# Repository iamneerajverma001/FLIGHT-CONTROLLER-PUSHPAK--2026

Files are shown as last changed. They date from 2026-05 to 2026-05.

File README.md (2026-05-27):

# Pushpak Flight Controller (FCV3)





[Download PCB ZIP](https://github.com/iamneerajverma001/FLIGHT-CONTROLLER-PUSHPAK--2026/archive/refs/heads/main.zip) · One-click download
[Open Portfolio App](https://cv6gnv.csb.app) · One-click interactive project summary

Quick links: [Visuals](#visuals) | [System overview](#system-overview) | [Core specs](#core-hardware-specifications) | [Block diagram](#block-diagram) | [Manufacturing](#manufacturing) | [Architecture](#architecture-deep-dive)

Pushpak FCV3 is a 36x36mm, 4-layer, noise-optimized flight controller built for high-performance FPV and autonomous payload delivery.

## Visuals
| Top view | Bottom view |
| --- | --- |
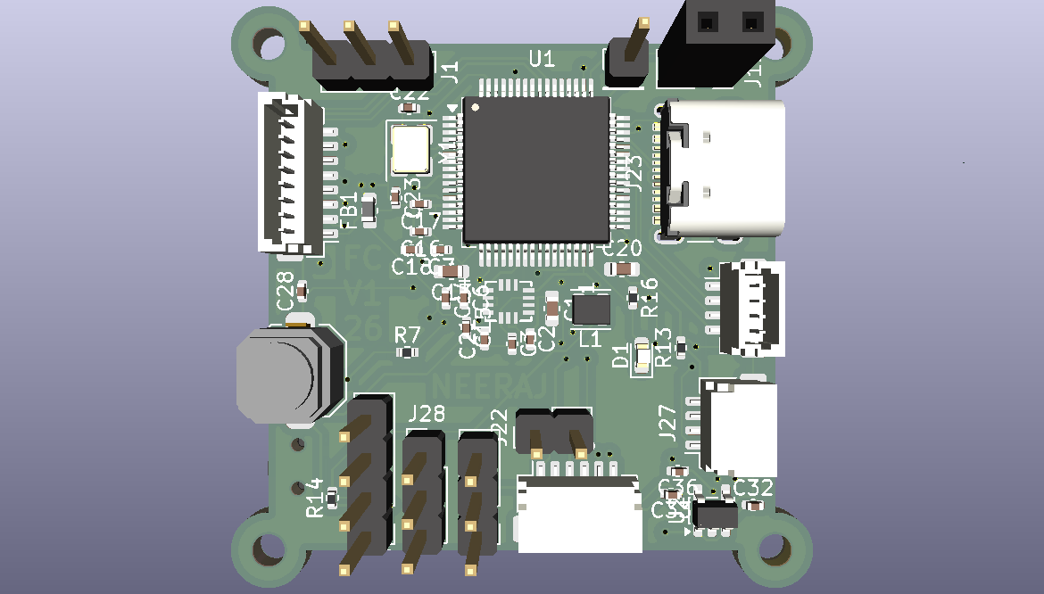
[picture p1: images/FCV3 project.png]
Top view
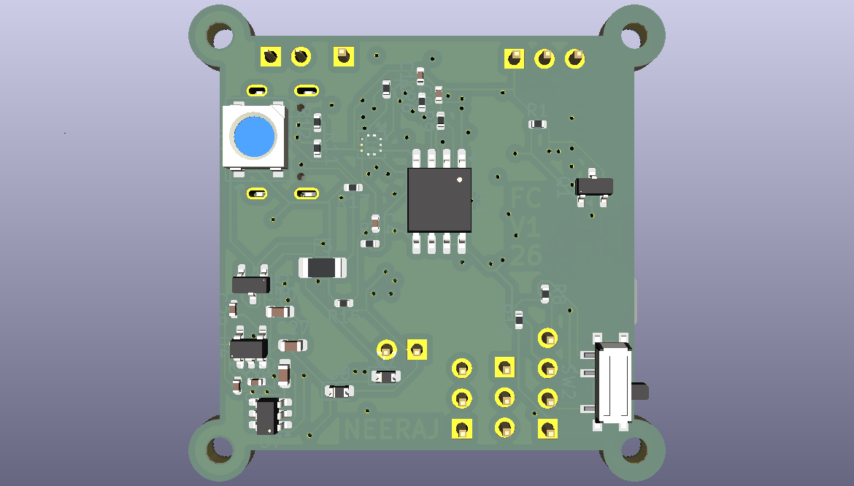
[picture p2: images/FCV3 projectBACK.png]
Bottom view
|  |  |

## System overview
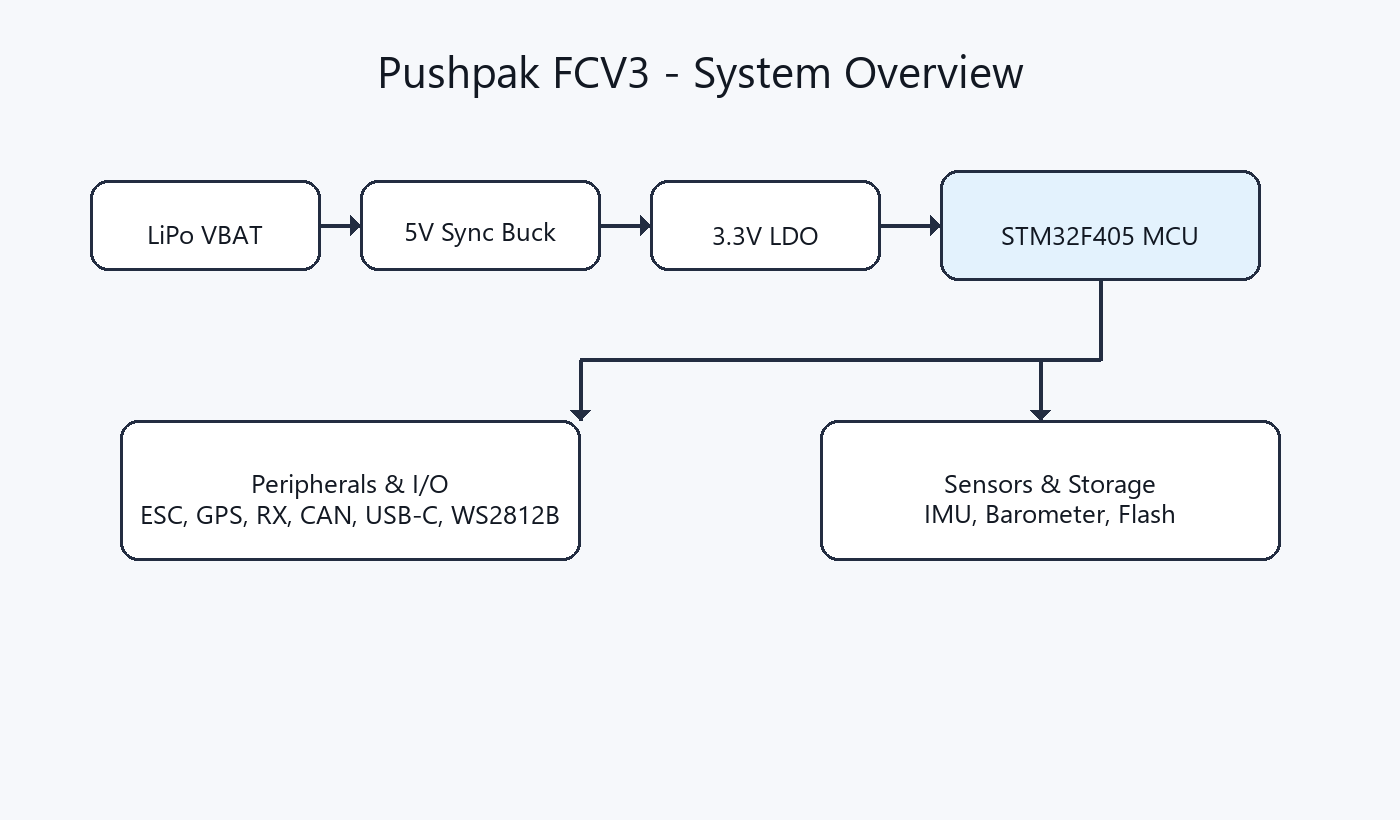
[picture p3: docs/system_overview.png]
System overview


## Key assets
| Asset | Location |
| --- | --- |
| KiCad project | [hardware/FCV3 project.kicad_pro](hardware/FCV3%20project.kicad_pro) |
| Architecture deep dive | [docs/HARDWARE_ARCHITECTURE.md](docs/HARDWARE_ARCHITECTURE.md) |
| System overview graphic | [docs/system_overview.png](docs/system_overview.png) |
| 3D model (VRML) | [outputs/FCV3 project.wrl](outputs/FCV3%20project.wrl) |
| Portfolio web app | [Open Portfolio App](https://cv6gnv.csb.app) |

## 3D model
- Board model (VRML): [outputs/FCV3 project.wrl](outputs/FCV3%20project.wrl)

## Block diagram
```mermaid
flowchart LR
  VBAT["LiPo VBAT"] --> BUCK["5V Sync Buck"]
  BUCK --> LDO["3.3V LDO"]
  LDO --> MCU["STM32F405"]
  MCU -->|SPI| IMU["ICM-42688-P"]
  MCU -->|I2C/SPI| BARO["BMP280 / BMP390"]
  MCU -->|SPI| FLASH["W25Q128"]
  MCU -->|Timers/DMA| ESC["4-in-1 ESC - DShot"]
  MCU -->|UART| GPS["GPS"]
  MCU -->|UART| RX["Radio Receiver"]
  MCU -->|CAN| CAN["DroneCAN"]
  MCU -->|USB| USBC["USB-C"]
  MCU -->|GPIO + BSS138| LED["WS2812B LEDs"]
```

## Core hardware specifications
- Processor: STM32F405RGT6 (ARM Cortex-M4) for high-speed calculation.
- IMU (Gyro): ICM-42688-P running on a dedicated ultra-fast SPI bus.
- Barometer: BMP280 / BMP390 for altitude hold.
- Blackbox: W25Q128 (16MB Flash) for flight data logging.
- Power delivery: High-efficiency 5V synchronous buck converter (MP1584 / TPS54202) taking raw LiPo voltage, paired with a clean 3.3V LDO for logic.

## Connectivity & I/O
- Motor control: 4-in-1 ESC connector (J21) with full hardware timer and DMA support for zero-latency DShot600.
- Expansions: DroneCAN telemetry, dedicated GPS port, and Radio Receiver port.
- Extras: WS2812B LED output (via BSS138 5V logic shifter) and USB-C for configuration.

## Repository navigation & usage
- hardware/ - KiCad project, schematic, PCB, and library tables.
- libraries/ - Custom symbols, footprints, and 3D models.
- outputs/ - BOM, reports, and manufacturing/export files.
- images/ - Board renders and screenshots.
- docs/ - Deep-dive design notes.

## How to open
1. Clone the repository.
2. Open [hardware/FCV3 project.kicad_pro](hardware/FCV3%20project.kicad_pro) in KiCad 8.0.

## Outputs
- BOM: [outputs/FCV3 project.csv](outputs/FCV3%20project.csv)
- ERC report: [outputs/ERC.rpt](outputs/ERC.rpt)
- Design report: [outputs/report.txt](outputs/report.txt)

## Manufacturing
Fabrication exports (Gerbers and Pick & Place/CPL) can be generated into outputs/ when you are ready to manufacture.

## Architecture deep dive
See the design intent and layout strategy in [docs/HARDWARE_ARCHITECTURE.md](docs/HARDWARE_ARCHITECTURE.md).

## Pinout quick view
For the full pinout tables, see [docs/HARDWARE_ARCHITECTURE.md](docs/HARDWARE_ARCHITECTURE.md).

### Core sensors and buses
| Feature | MCU Pin | Bus | Component |
| --- | --- | --- | --- |
| Gyro CS | PA4 | SPI1 | ICM-42688-P |
| Gyro SCK | PA5 | SPI1 | ICM-42688-P |
| Gyro MISO | PA6 | SPI1 | ICM-42688-P |
| Gyro MOSI | PA7 | SPI1 | ICM-42688-P |
| Flash CS | PA15 | SPI3 | W25Q128 |
| Flash SCK | PC10 | SPI3 | W25Q128 |
| Flash MISO | PC11 | SPI3 | W25Q128 |
| Flash MOSI | PC12 | SPI3 | W25Q128 |
| Baro SCL | PA8 | I2C3 | BMP280 / BMP390 |
| Baro SDA | PC9 | I2C3 | BMP280 / BMP390 |

### Motor and payload outputs
| Output | MCU Pin | Timer | Connection |
| --- | --- | --- | --- |
| Motor 1 | PB3 | TIM2_CH2 | J21 ESC port |
| Motor 2 | PB10 | TIM2_CH3 | J21 ESC port |
| Motor 3 | PB2 | TIM2_CH4 | J21 ESC port |
| Motor 4 | PB4 | TIM3_CH1 | J21 ESC port |
| Motor 5 | PB0 | TIM3_CH3 | Expansion |
| Motor 6 | PB14 | TIM12_CH1 | Expansion |
| Servo 1 | PB15 | TIM12_CH2 | Payload / gimbal |

## Challenges & learnings
- Stackup discipline and clean partitioning were critical to keeping gyro noise low.
- Layout geometry matters as much as routing for flight stability.
- Tight power loops and ground shielding reduced EMI from the buck stage.

## License
Project files are licensed under [LICENSE](LICENSE).
Library components are provided under the terms in [license.txt](license.txt).

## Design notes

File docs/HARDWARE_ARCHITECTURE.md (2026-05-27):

# Hardware Architecture

This document focuses on the design intent behind the layout, stackup, and signal integrity choices.

## Visual references
- Renders: ../images/FCV3 project.png (top), ../images/FCV3 projectBACK.png (bottom).
- 3D model: ../outputs/FCV3 project.wrl.
- System overview: system_overview.png.

## Design goals
- Keep sensor noise low while maintaining fast control loop response.
- Maintain short, direct high-speed routes for the gyro and flash.
- Isolate power switching energy from sensitive analog rails.

## Block diagram
```mermaid
flowchart LR
  VBAT["LiPo VBAT"] --> BUCK["5V Sync Buck"]
  BUCK --> LDO["3.3V LDO"]
  LDO --> MCU["STM32F405"]
  MCU -->|SPI| IMU["ICM-42688-P"]
  MCU -->|I2C/SPI| BARO["BMP280 / BMP390"]
  MCU -->|SPI| FLASH["W25Q128"]
  MCU -->|Timers/DMA| ESC["4-in-1 ESC - DShot"]
  MCU -->|UART| GPS["GPS"]
  MCU -->|UART| RX["Radio Receiver"]
  MCU -->|CAN| CAN["DroneCAN"]
  MCU -->|USB| USBC["USB-C"]
  MCU -->|GPIO + BSS138| LED["WS2812B LEDs"]
```

## Master MCU pinout mapping (STM32F4 series)

### Core sensors (internal buses)
| Feature | MCU Pin | Bus / Timer | Component / Function |
| --- | --- | --- | --- |
| Gyro CS | PA4 | SPI1 | ICM-42688-P chip select |
| Gyro SCK | PA5 | SPI1 | ICM-42688-P clock |
| Gyro MISO | PA6 | SPI1 | ICM-42688-P data out |
| Gyro MOSI | PA7 | SPI1 | ICM-42688-P data in |
| Flash CS | PA15 | SPI3 | W25Q128 blackbox chip select |
| Flash SCK | PC10 | SPI3 | W25Q128 blackbox clock |
| Flash MISO | PC11 | SPI3 | W25Q128 blackbox data out |
| Flash MOSI | PC12 | SPI3 | W25Q128 blackbox data in |
| Baro SCL | PA8 | I2C3 | BMP280 / BMP390 clock |
| Baro SDA | PC9 | I2C3 | BMP280 / BMP390 data |

### Propulsion and actuation (DShot and PWM)
| Feature | MCU Pin | Hardware Timer | Physical Connection |
| --- | --- | --- | --- |
| Motor 1 | PB3 | TIM2_CH2 | J21 (4-in-1 ESC port) |
| Motor 2 | PB10 | TIM2_CH3 | J21 (4-in-1 ESC port) |
| Motor 3 | PB2 | TIM2_CH4 | J21 (4-in-1 ESC port) |
| Motor 4 | PB4 | TIM3_CH1 | J21 (4-in-1 ESC port) |
| Motor 5 | PB0 | TIM3_CH3 | Expansion / standalone ESC |
| Motor 6 | PB14 | TIM12_CH1 | Expansion / standalone ESC |
| Servo 1 | PB15 | TIM12_CH2 | Payload drop / camera gimbal |

### Serial connectivity (UART and I2C)
| Feature | MCU Pin | Protocol | Dedicated Function |
| --- | --- | --- | --- |
| GPS TX | PA0 | UART4 | M10/M9 GPS module RX |
| GPS RX | PA1 | UART4 | M10/M9 GPS module TX |
| Radio TX | PA9 | USART1 | ELRS / Crossfire RX |
| Radio RX | PA10 | USART1 | ELRS / Crossfire TX / SBUS |
| ESC RX | PC7 | USART6 | ESC digital telemetry (J21) |
| Ext SCL | PB6 | I2C1 | External compass clock (pulled up) |
| Ext SDA | PB7 | I2C1 | External compass data (pulled up) |
| CAN RX | PB12 | CAN2 | DroneCAN expansion |
| CAN TX | PB13 | CAN2 | DroneCAN expansion |

### Analog inputs (ADC) and lighting
| Feature | MCU Pin | Filter Type | Physical Connection |
| --- | --- | --- | --- |
| Current sensor | PC0 | RC low-pass | ADC1_IN0 (J21 ESC port) |
| Voltage / RSSI | PC5 | RC low-pass | ADC2_IN / VBAT sense |
| Status LED | PB5 | 5V logic shifter | WS2812B data in |

### System and debug
| Feature | MCU Pin | Function | Physical Connection |
| --- | --- | --- | --- |
| USB D- | PA11 | USB-FS | USB-C connector |
| USB D+ | PA12 | USB-FS | USB-C connector |
| SWDIO | PA13 | SWD debug | J11 debug pads |
| SWCLK | PA14 | SWD debug | J11 debug pads |
| OSC IN | PH0 | 8MHz HSE | External crystal |
| OSC OUT | PH1 | 8MHz HSE | External crystal |

## Peripheral mapping and I/O connectivity

### Propulsion and ESC integration (J21 connector)
- Motor outputs (M1 - M4) are mapped to hardware timers (TIM2/TIM3) with DMA support for DShot600 and bidirectional DShot.
- Current sensor input is routed through a dedicated RC low-pass filter before the STM32 ADC.
- VBAT enters the bottom-layer power plant for 5V regulation.

### Radio and telemetry (digital standard)
- Radio receiver port (USART1) is optimized for ELRS, Crossfire, and SBUS. Analog RSSI pads are intentionally omitted.
- ESC telemetry (USART6) provides digital RPM, temperature, and error data from modern ESCs.

### Autonomous navigation (GPS and compass)
- GPS interface (UART4) is dedicated to M10/M8/M9 modules.
- External magnetometer (I2C1) is exposed with onboard 4.7k pull-ups.

### Payload and actuation expansions
- WS2812B LED data is driven through a BSS138 level shifter for reliable 5V signaling.
- Servo and payload PWM pads use hardware timers (TIM12) for deterministic control.

### Configuration and debugging
- USB-C provides high-reliability USB-FS for configuration and logging.
- Bootloader access is supported by a physical BOOT0 button tied to 3.3V.
- SWDIO and SWCLK pads enable bare-metal debugging and firmware bring-up.

## PCB stackup strategy (4-layer strict standard)
- Layer 1 (Top / F.Cu) - The Quiet Zone. This layer hosts the MCU, sensors, and the highest-speed data traces only.
- Layer 2 (Inner 1) - The Shield. A solid GND plane that shields the sensitive top layer from bottom-layer noise.
- Layer 3 (Inner 2) - Power Routing. Dedicated 3V3 and 5V copper polygons for low-impedance delivery.
- Layer 4 (Bottom / B.Cu) - The Power & Noise Zone. High-current VBAT routing and the buck converter stay here.

## Component placement & layout logic
- Gyro positioning: The ICM-42688-P is placed at the geometric center of the 36x36mm board for balanced flight physics.
- MCU orientation: The STM32 is rotated so its SPI1 pins face the gyro, keeping critical traces short and straight.
- Power supply isolation: The 5V buck converter, inductor, and diode are clustered in a single bottom-layer corner to confine magnetic noise.
- Thermal management: The barometer sits in the corner opposite the power supply to reduce heat-induced altitude drift.

## Signal integrity & noise immunity
- Analog low-pass filtering: Ferrite bead + multi-cap decoupling on VDDA and current sensor lines scrub ESC noise before the ADC.
- Decoupling strategy: All 0.1uF caps are placed directly under MCU pins and via'd straight down to minimize loop inductance.
- Logic level shifting: A BSS138 N-channel MOSFET shifts 3.3V MCU GPIO to 5V WS2812B logic to prevent flicker.

## Challenges & learnings
- Balanced mechanical layout improves IMU accuracy and reduces tuning noise.
- Short, direct SPI routes reduce overshoot and make gyro sampling more reliable.
- Power partitioning and a solid GND shield reduce ESC noise coupling into the analog domain.

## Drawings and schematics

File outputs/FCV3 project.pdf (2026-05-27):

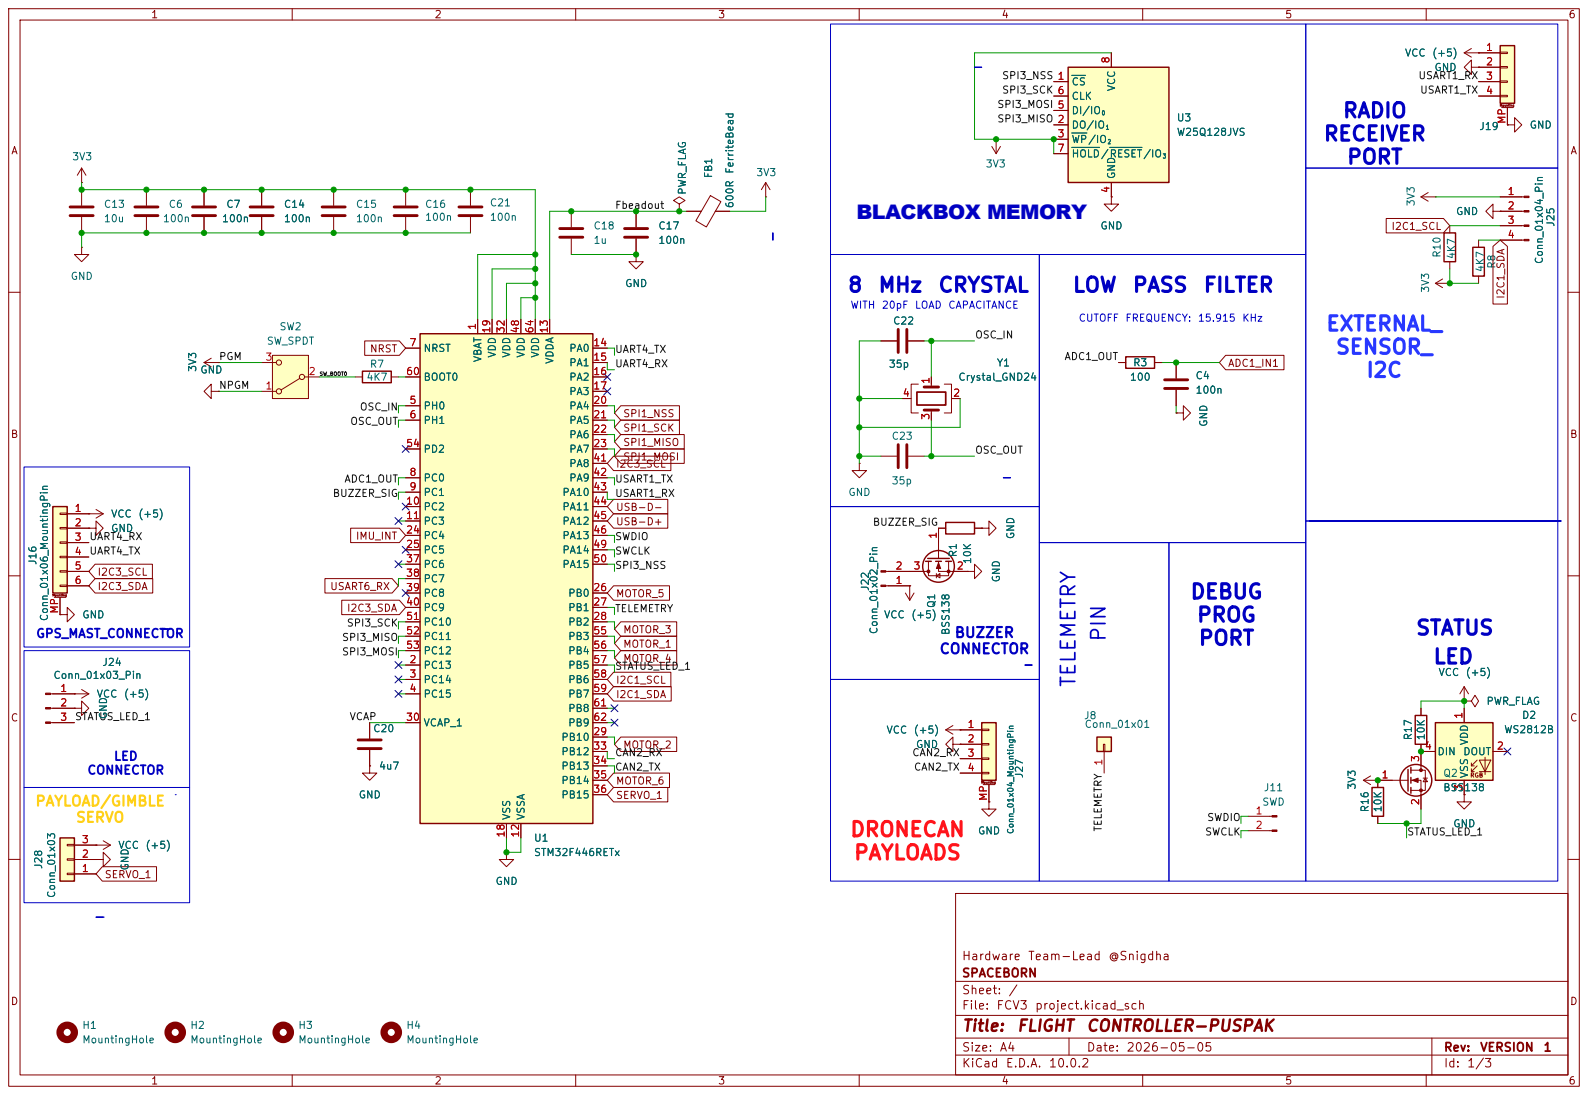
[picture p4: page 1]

4 DI/IO0 5 CLK 6 HOLD/RESET/IO3 7 VCC

WITH 20pF LOAD CAPACITANCE 8 MHz CRYSTAL

2 3 Q2BSS138 VBAT 1 PC13 2 PC14 3 PC15 4 PH0 5 PH1 6 NRST 7 PC0 8 PC1 9 PC2 10 PC3 11 VSSA 12 VDDA 13 PA0 14 PA1 15 PA2 16 PA3 17 VSS 18 VDD 19 PA4 20 PA5 21 PA6 22 PA7 23 PC4 24 PC5 25 PB0 26 PB1 27 PB2 28 PB10 29 VCAP_1 30 VDD 32 PB12 33 PB13 34 PB14 35 PB15 36 PC6 37 PC7 38 PC8 39 PC9 40 PA8 41 PA9 42 PA10 43 PA11 44 PA12 45 PA13 46 VDD 48 PA14 49 PA15 50 PC10 51 PC11 52 PC12 53 PD2 54 PB3 55 PB4 56 PB5 57 PB6 58 PB7 59 BOOT0 60 PB8 61 PB9 62 VDD 64 U1

CUTOFF FREQUENCY: 15.915 KHz DEBUG

Hardware Team-Lead @Snigdha
SPACEBORN
Sheet: /
File: FCV3 project.kicad_sch
Title: FLIGHT CONTROLLER-PUSPAK

Size: A4 | Rev: VERSION 1
KiCad E.D.A. 10.0.2 | Id: 1/3

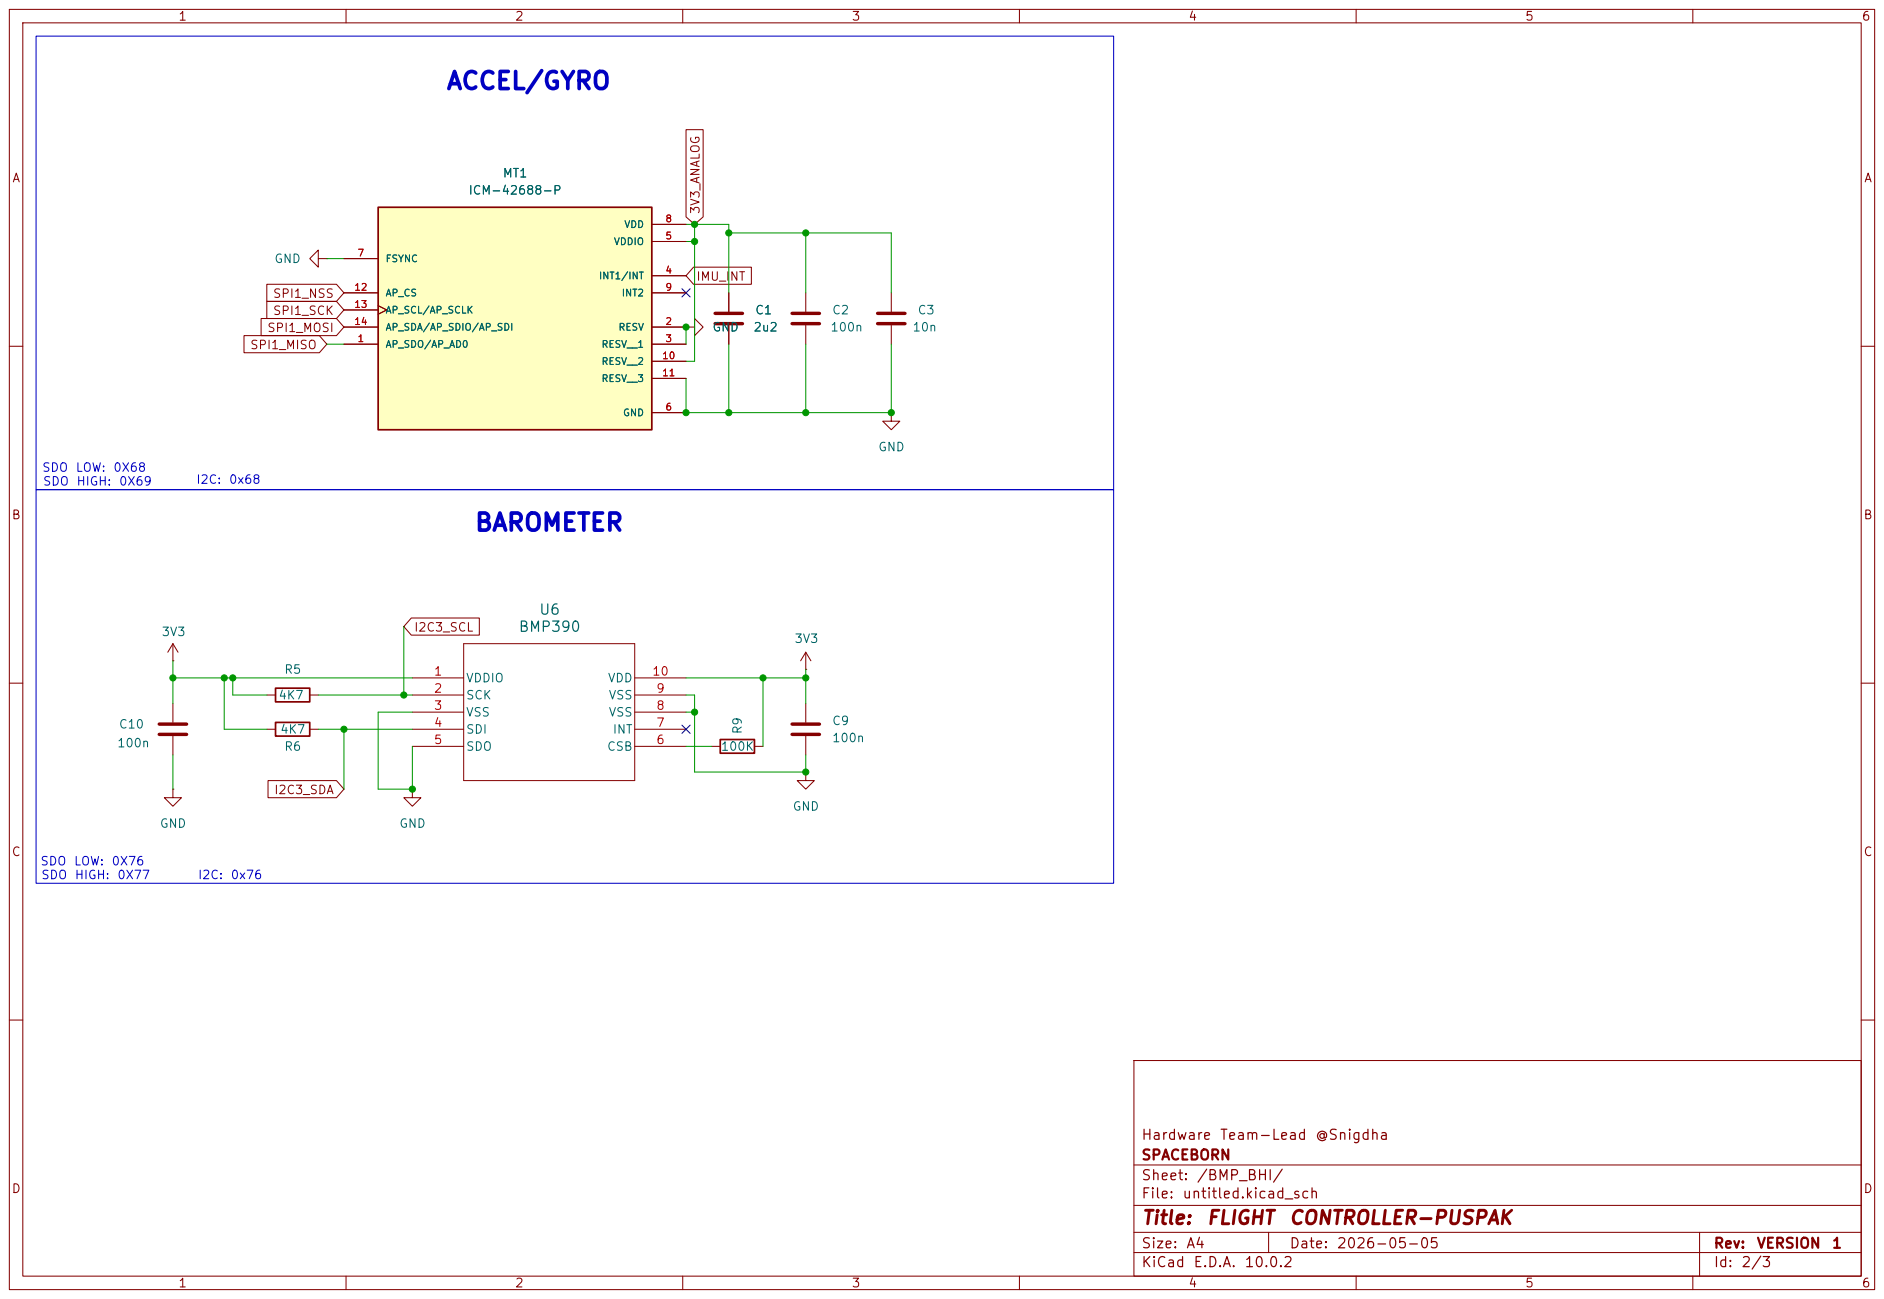
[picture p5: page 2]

SDO LOW: 0X76 SDO HIGH: 0X77

Hardware Team-Lead @Snigdha
SPACEBORN
Sheet: /BMP_BHI/
File: untitled.kicad_sch
Title: FLIGHT CONTROLLER-PUSPAK

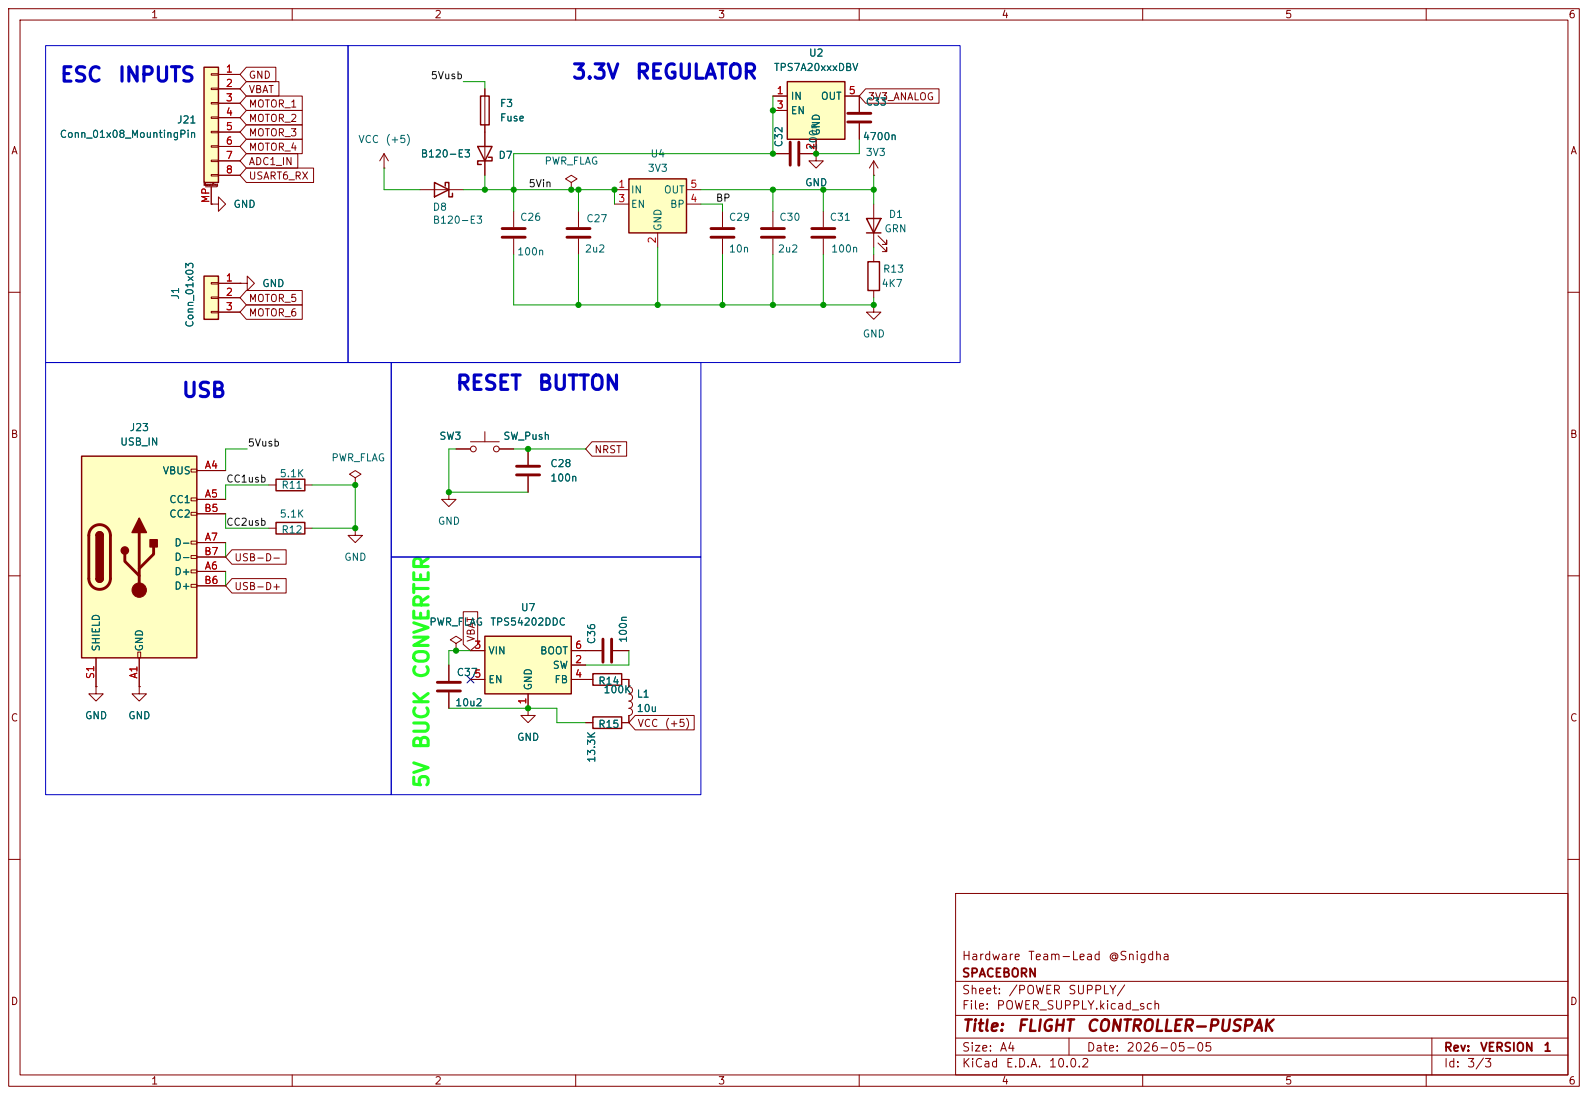
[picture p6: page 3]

RESET BUTTON 5V BUCK CONVERTER

Hardware Team-Lead @Snigdha
SPACEBORN
Sheet: /POWER SUPPLY/
File: POWER_SUPPLY.kicad_sch
Title: FLIGHT CONTROLLER-PUSPAK

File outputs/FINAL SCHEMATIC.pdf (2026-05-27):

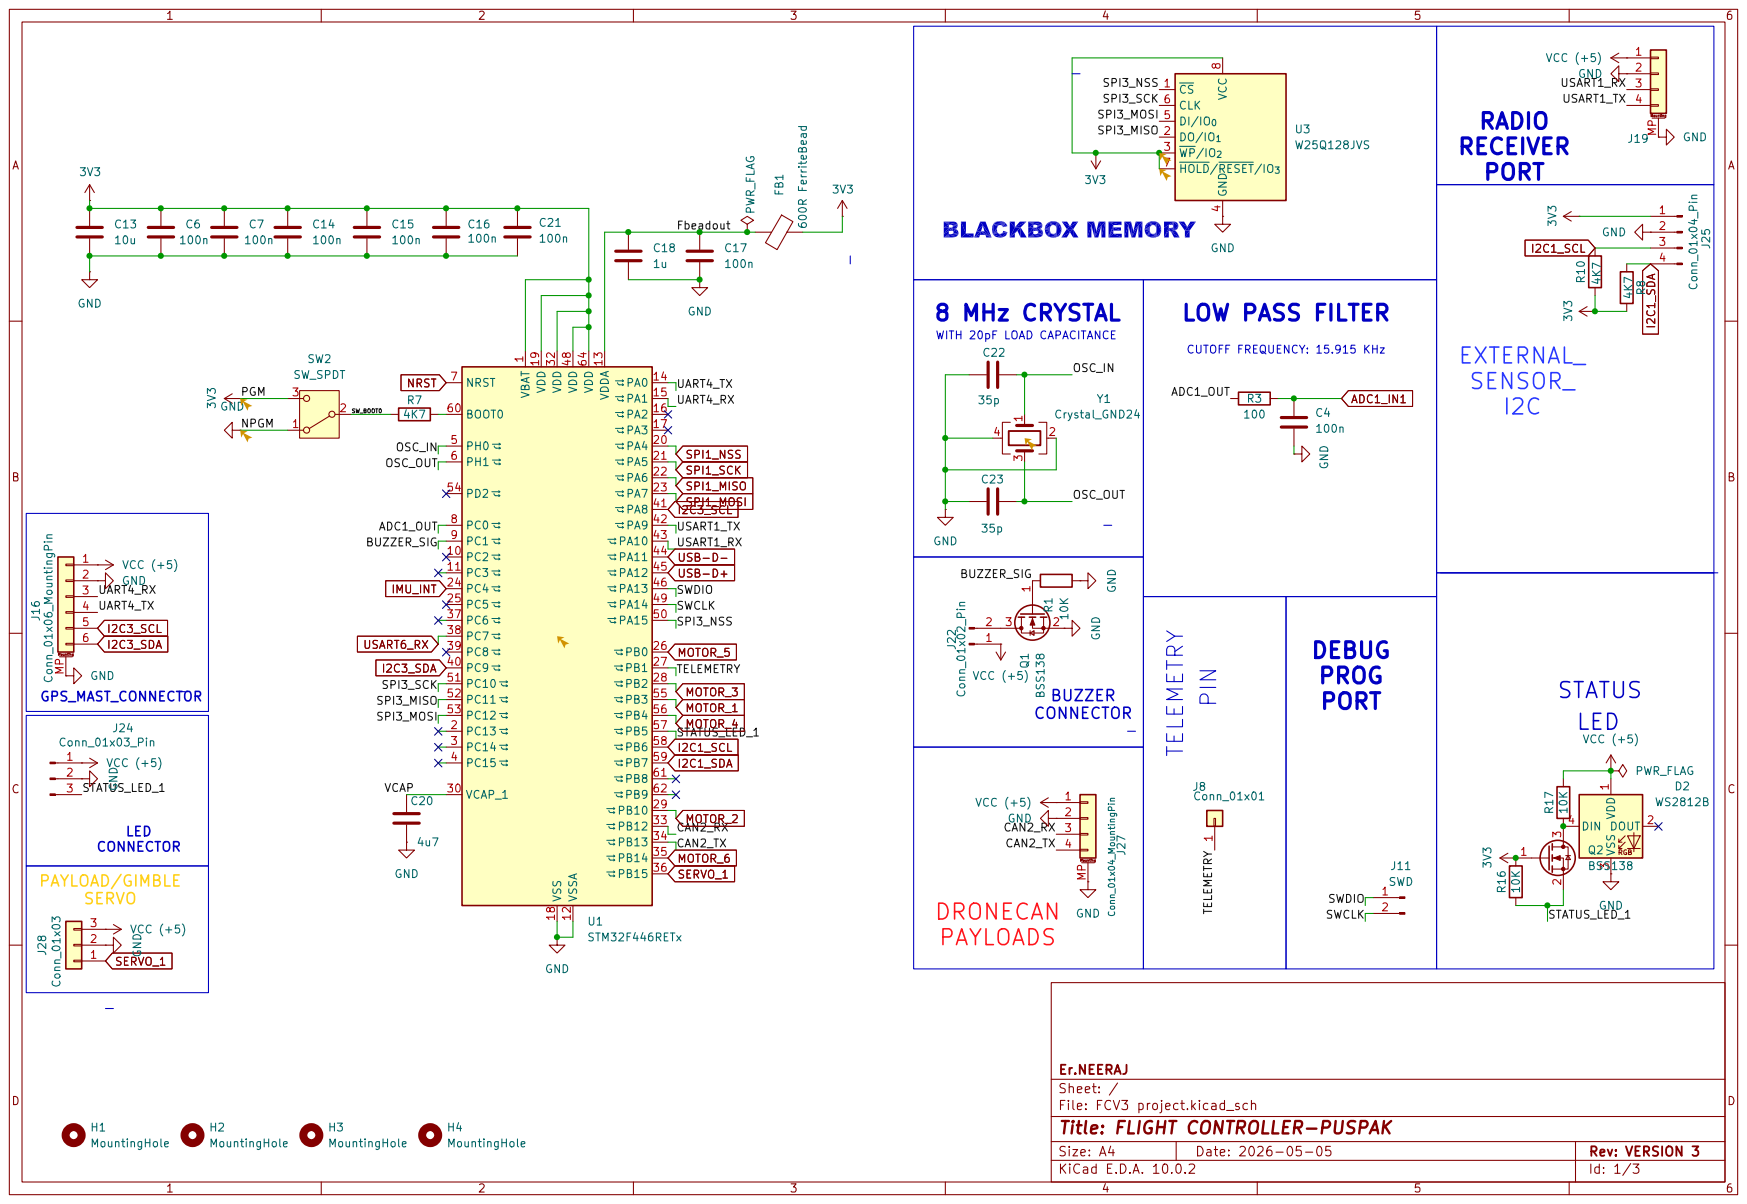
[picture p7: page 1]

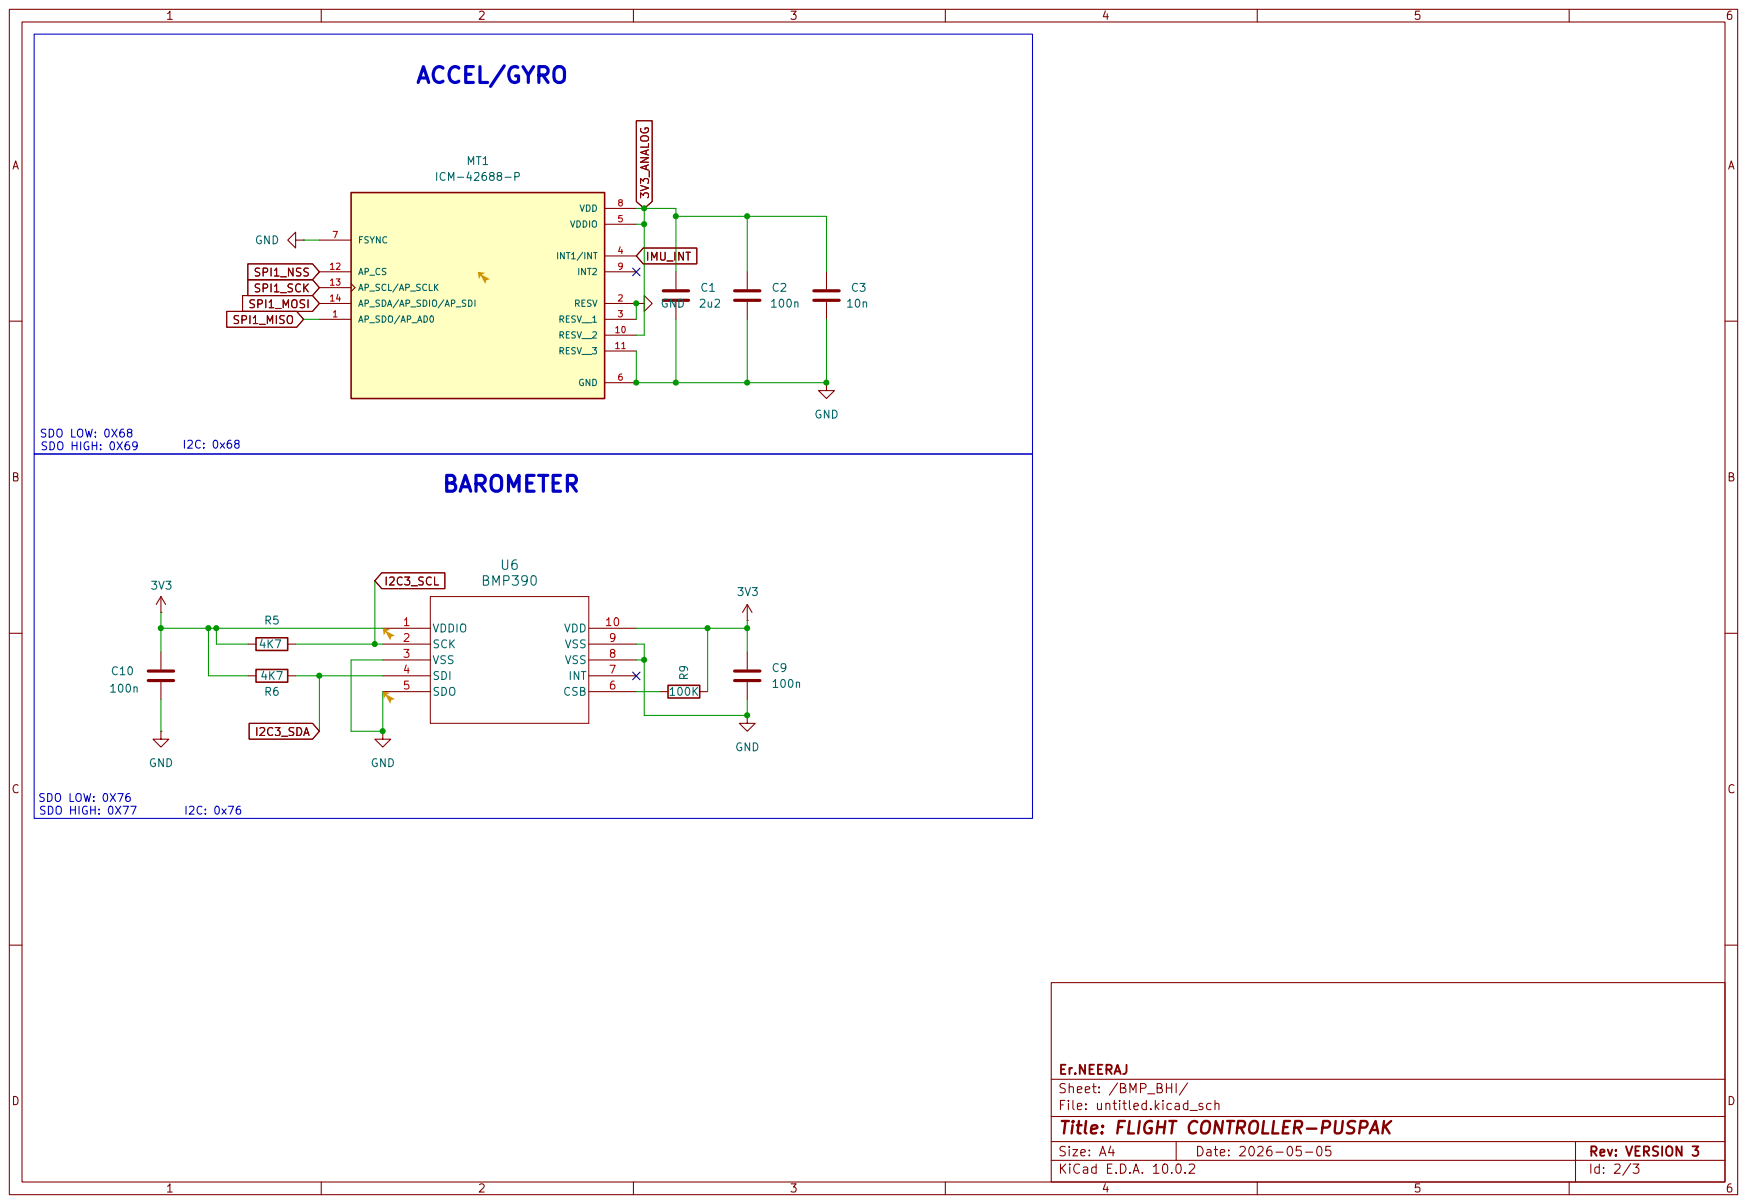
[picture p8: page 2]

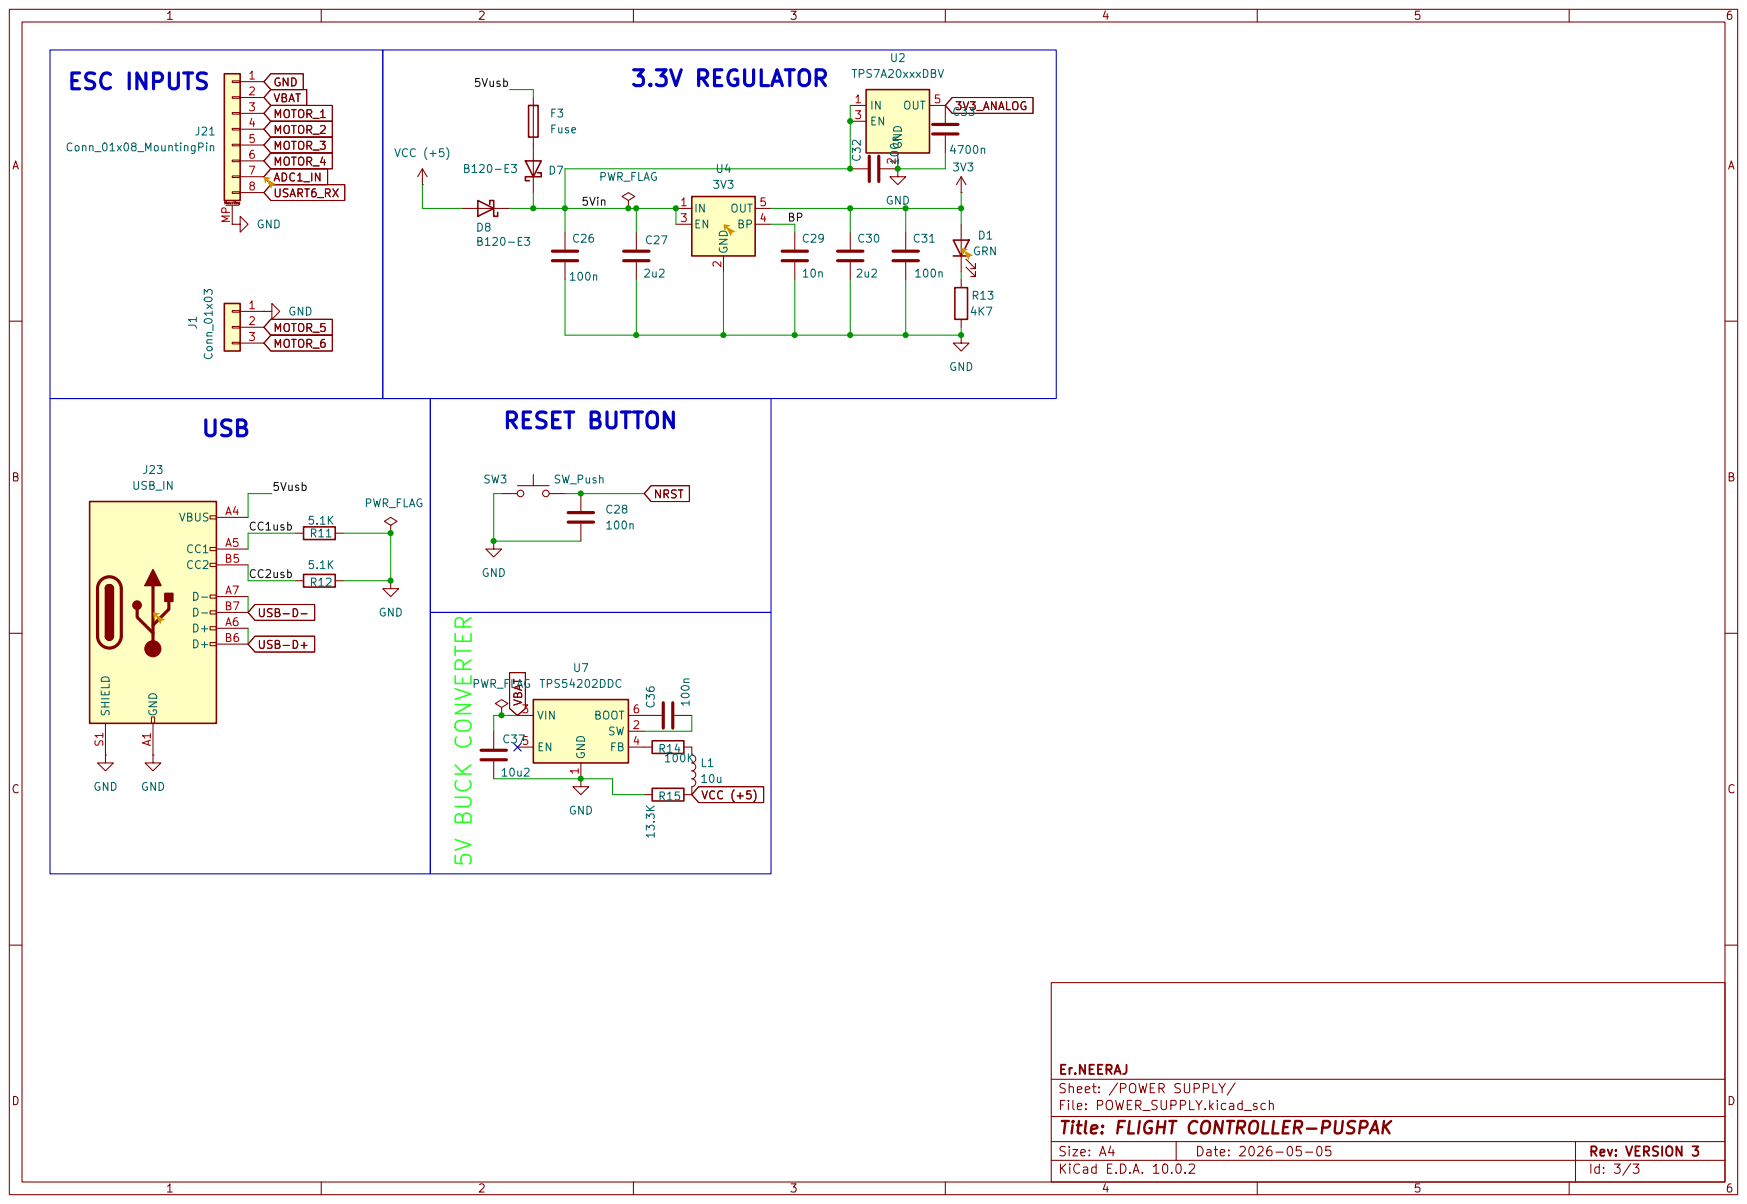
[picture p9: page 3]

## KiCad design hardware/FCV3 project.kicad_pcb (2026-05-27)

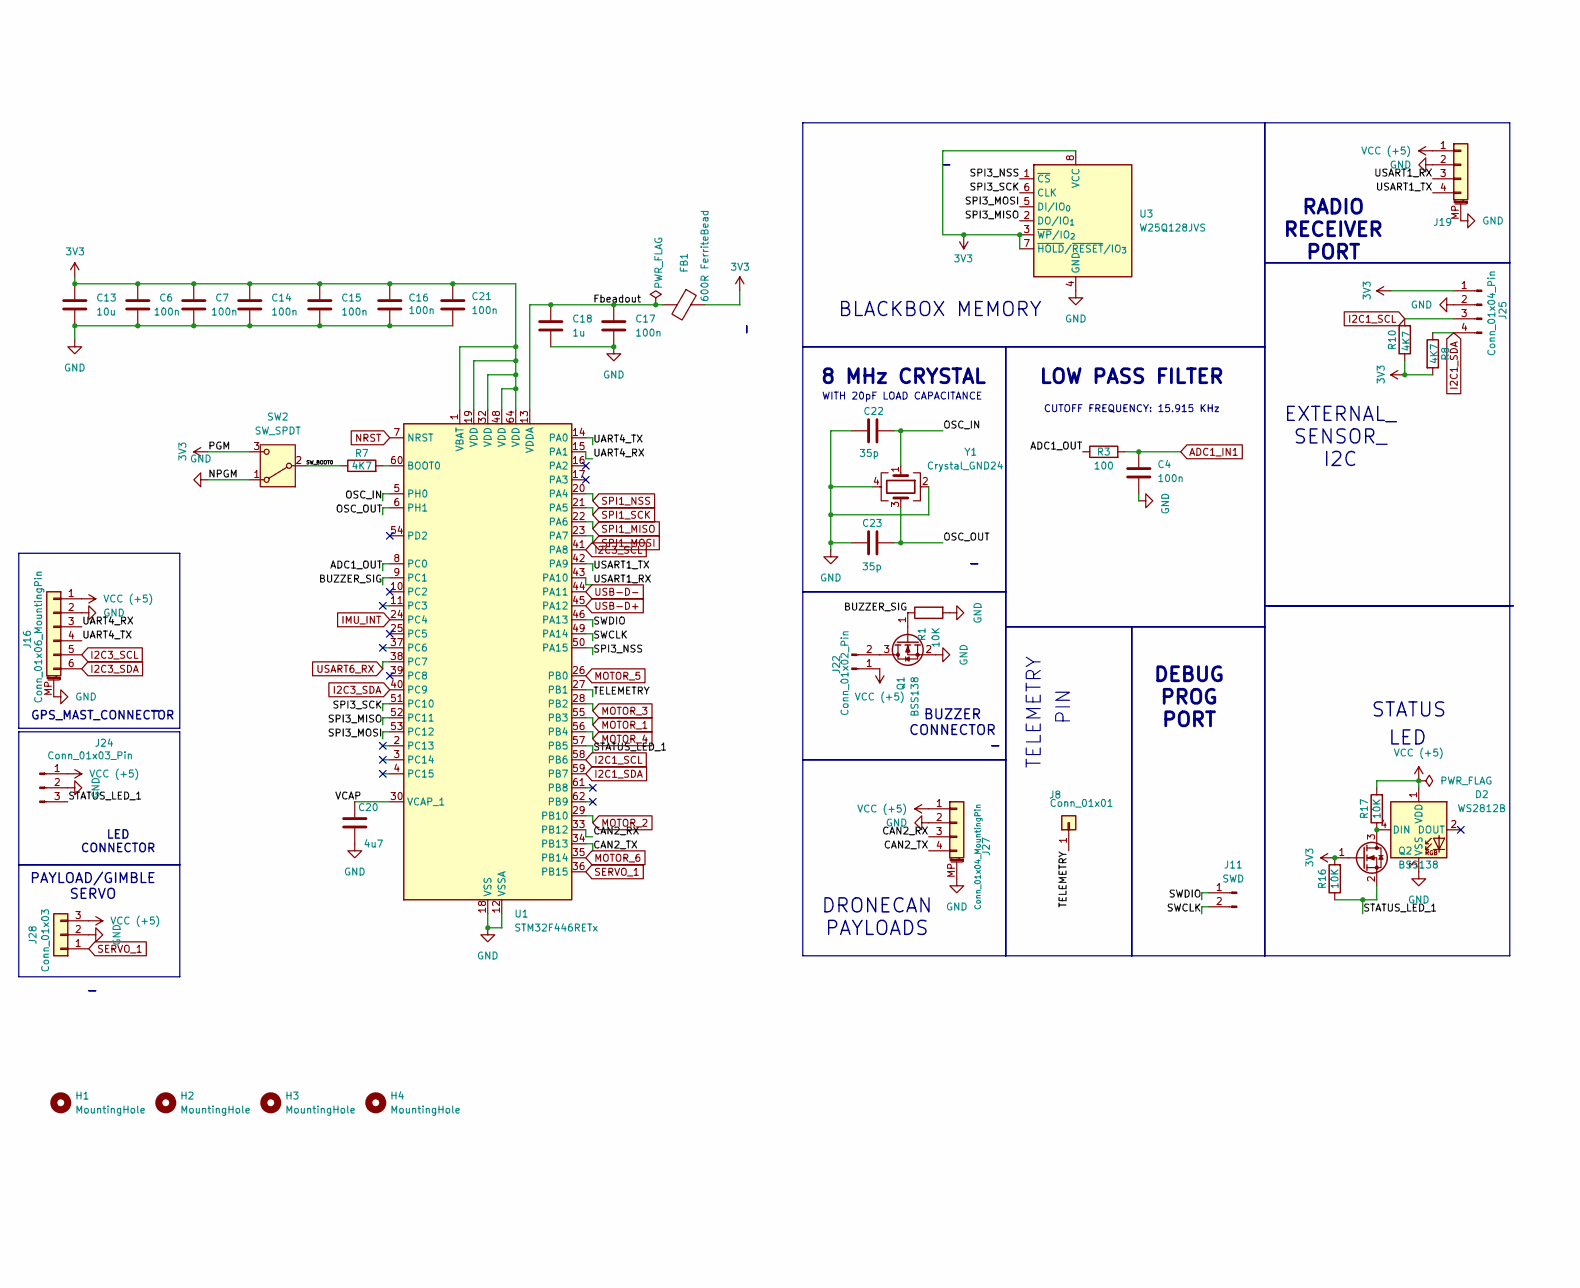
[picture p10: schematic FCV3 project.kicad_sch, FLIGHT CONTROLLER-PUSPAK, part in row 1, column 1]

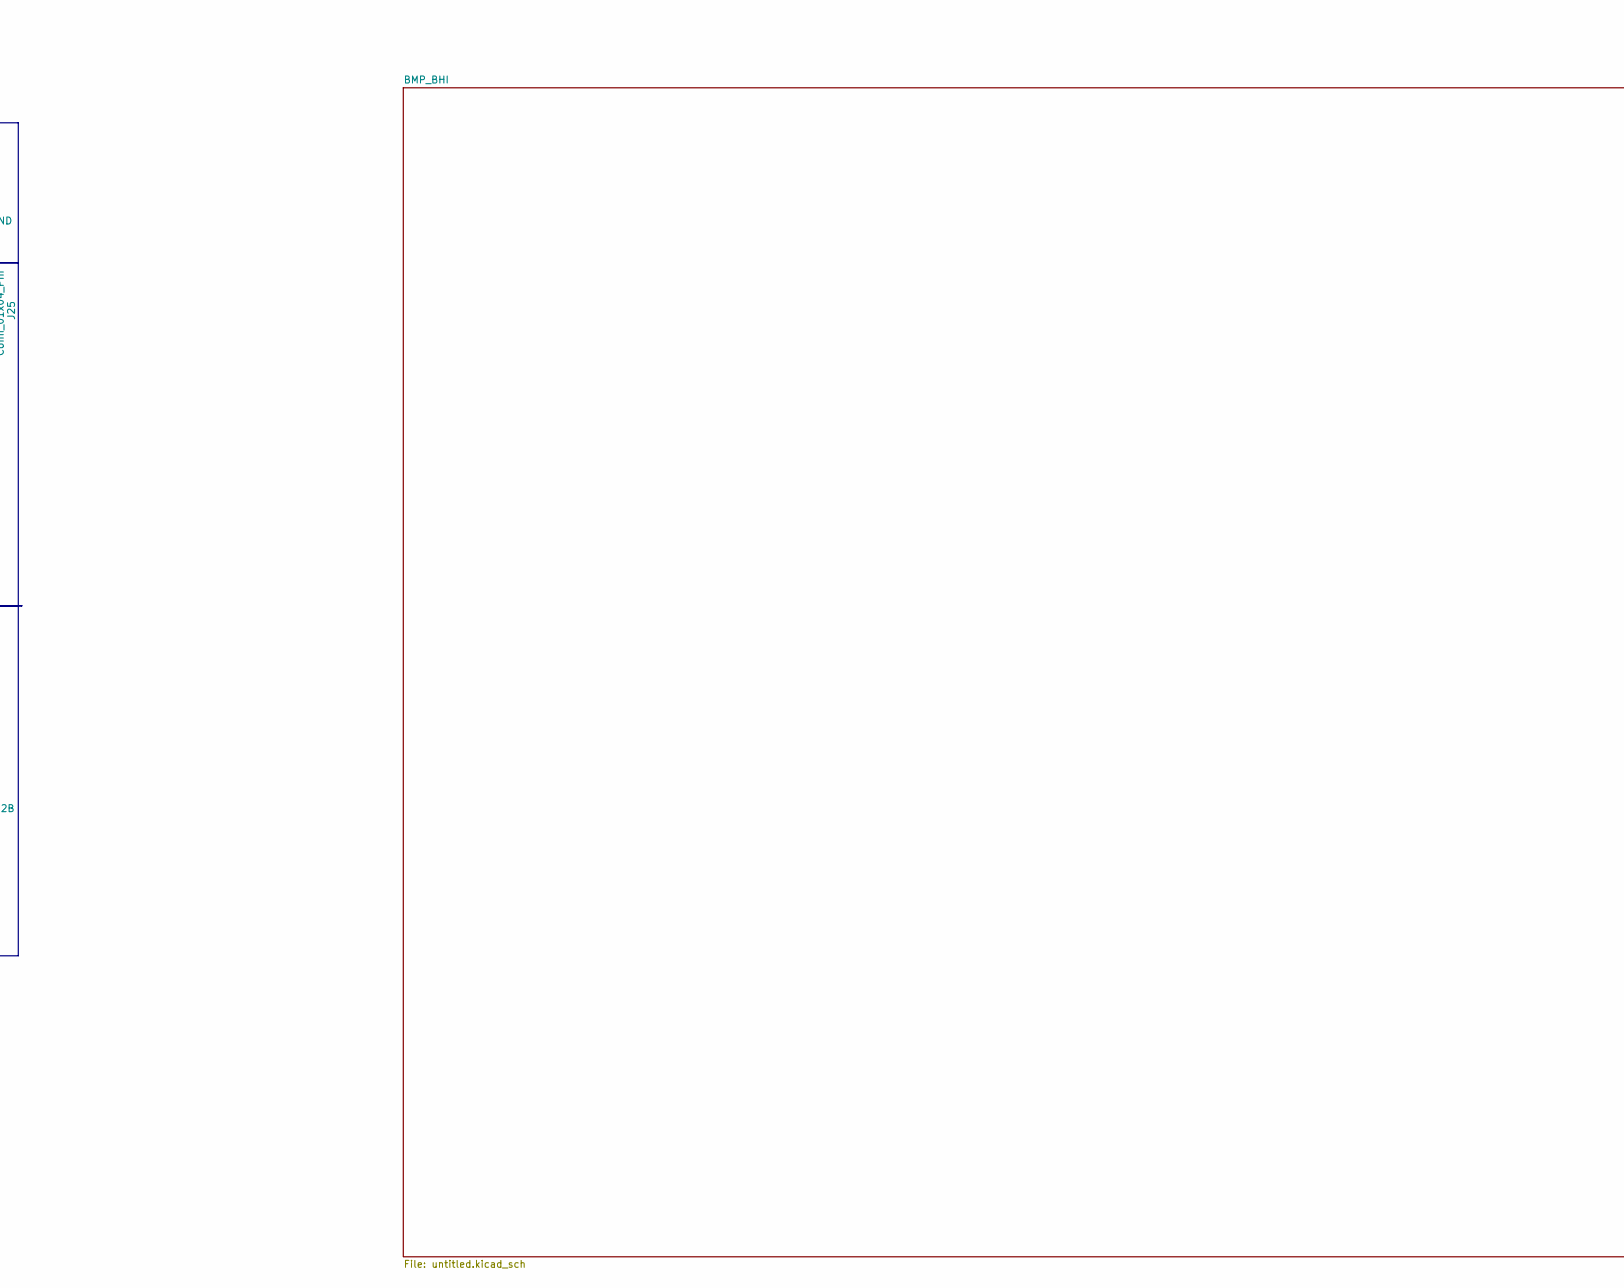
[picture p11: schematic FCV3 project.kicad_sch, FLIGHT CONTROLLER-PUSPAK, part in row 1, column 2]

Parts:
C4, C6, C7, C14, C15, C16, C17, C21: 100n; C_0402_1005Metric
C13: 10u; C_0603_1608Metric
C18: 1u; C_0402_1005Metric
C20: 4u7; C_0603_1608Metric
C22, C23: 35p; C_0402_1005Metric
D2: WS2812B; LED_WS2812B_PLCC4_5.0x5.0mm_P3.2mm
FB1: 600R FerriteBead; L_0603_1608Metric
H1, H2, H3, H4: MountingHole; MountingHole_2.2mm_M2
J8: Conn_01x01; PinHeader_1x01_P2.54mm_Vertical
J11: SWD; PinSocket_1x02_P2.54mm_Vertical
J16: Conn_01x06_MountingPin; JST_SH_SM06B-SRSS-TB_1x06-1MP_P1.00mm_Horizontal
J19: RADIO; JST_SH_BM04B-SRSS-TB_1x04-1MP_P1.00mm_Vertical
J22: Conn_01x02_Pin; PinHeader_1x02_P2.54mm_Vertical
J24: Conn_01x03_Pin; PinHeader_1x03_P2.54mm_Vertical
J25: Conn_01x04_Pin; PinHeader_1x04_P2.54mm_Vertical
J27: Conn_01x04_MountingPin; JST_SH_SM04B-SRSS-TB_1x04-1MP_P1.00mm_Horizontal
J28: Conn_01x03; PinHeader_1x03_P2.54mm_Vertical
Q1, Q2: BSS138; SOT-23
R1, R16, R17: 10K; R_0402_1005Metric
R3: 100; R_0402_1005Metric
R7, R8, R10: 4K7; R_0402_1005Metric
SW2: SW_SPDT; SW_SPDT_PCM12
U1: STM32F446RETx; LQFP-64_10x10mm_P0.5mm
U3: W25Q128JVS; SOIC-8_5.3x5.3mm_P1.27mm
Y1: Crystal_GND24; Crystal_SMD_3225-4Pin_3.2x2.5mm

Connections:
3V3: C6.1, C7.1, C13.1, C14.1, C15.1, C16.1, C21.2, FB1.1, J25.1, Q2.1 (G), R8.2, R10.1, R16.2, SW2.3 (C), U1.1 (VBAT), U1.19 (VDD), U1.32 (VDD), U1.48 (VDD), U1.64 (VDD), U3.3 (~WP/IO_{2}), U3.7 (~HOLD/~RESET/IO_{3}), U3.8 (VCC); also elsewhere on the board
/ADC1_OUT: R3.1, U1.8 (PC0)
/BUZZER_SIG: Q1.1 (G), R1.1, U1.9 (PC1)
/CAN2_RX: J27.3, U1.33 (PB12)
/CAN2_TX: J27.4, U1.34 (PB13)
/Fbeadout: C17.1, C18.1, FB1.2, U1.13 (VDDA)
/OSC_IN: C22.1, U1.5 (PH0), Y1.1
/OSC_OUT: C23.1, U1.6 (PH1), Y1.3
/SPI3_MISO: U1.52 (PC11), U3.2 (DO/IO_{1})
/SPI3_MOSI: U1.53 (PC12), U3.5 (DI/IO_{0})
/SPI3_NSS: U1.50 (PA15), U3.1 (~CS)
/SPI3_SCK: U1.51 (PC10), U3.6 (CLK)
/STATUS_LED_1: J24.3, Q2.2 (S), R16.1, U1.57 (PB5)
/SWCLK: J11.2, U1.49 (PA14)
/SWDIO: J11.1, U1.46 (PA13)
/SW_BOOT0: R7.1, SW2.2 (B)
/TELEMETRY: J8.1 (Pin_1_1), U1.27 (PB1)
/UART4_RX: J16.3, U1.15 (PA1)
/UART4_TX: J16.4, U1.14 (PA0)
/USART1_RX: J19.3, U1.43 (PA10)
/USART1_TX: J19.4, U1.42 (PA9)
/VCAP: C20.1, U1.30 (VCAP_1)
ADC1_IN1: C4.2, R3.2
GND: C4.1, C6.2, C7.2, C13.2, C14.2, C15.2, C16.2, C17.2, C18.2, C20.2, C21.1, C22.2, C23.2, D2.3 (VSS), J16.2, J16.MP (MountPin), J19.2, J19.MP (MountPin), J24.2, J25.2, J27.2, J27.MP (MountPin), J28.2, Q1.2 (S), R1.2, SW2.1 (A), U1.12 (VSSA), U1.18 (VSS), U1.31 (VSS), U1.47 (VSS), U1.63 (VSS), U3.4 (GND), Y1.2, Y1.4; also elsewhere on the board
I2C1_SCL: J25.3, R10.2, U1.58 (PB6)
I2C1_SDA: J25.4, R8.1, U1.59 (PB7)
I2C3_SCL: J16.5, U1.41 (PA8); also elsewhere on the board
I2C3_SDA: J16.6, U1.40 (PC9); also elsewhere on the board
IMU_INT: U1.24 (PC4); also elsewhere on the board
MOTOR_1: U1.55 (PB3); also elsewhere on the board
MOTOR_2: U1.29 (PB10); also elsewhere on the board
MOTOR_3: U1.28 (PB2); also elsewhere on the board
MOTOR_4: U1.56 (PB4); also elsewhere on the board
MOTOR_5: U1.26 (PB0); also elsewhere on the board
MOTOR_6: U1.35 (PB14); also elsewhere on the board
NRST: U1.7 (NRST); also elsewhere on the board
unnamed: D2.4 (DIN), Q2.3 (D), R17.1
unnamed: J22.2, Q1.3 (D)
unnamed: R7.2, U1.60 (BOOT0)
SERVO_1: J28.1, U1.36 (PB15)
SPI1_MISO: U1.22 (PA6); also elsewhere on the board
SPI1_MOSI: U1.23 (PA7); also elsewhere on the board
SPI1_NSS: U1.20 (PA4); also elsewhere on the board
SPI1_SCK: U1.21 (PA5); also elsewhere on the board
USART6_RX: U1.38 (PC7); also elsewhere on the board
USB-D+: U1.45 (PA12); also elsewhere on the board
USB-D-: U1.44 (PA11); also elsewhere on the board
VCC (+5): D2.1 (VDD), J16.1, J19.1, J22.1, J24.1, J27.1, J28.3, R17.2; also elsewhere on the board

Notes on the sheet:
PAYLOAD/GIMBLE SERVO
RADIO RECEIVER PORT
LED
BLACKBOX MEMORY
GPS_MAST_CONNECTOR
EXTERNAL_ SENSOR_ I2C
CUTOFF FREQUENCY: 15.915 KHz
LOW PASS FILTER
PIN
DRONECAN PAYLOADS
TELEMETRY
LED CONNECTOR
DEBUG PROG PORT
8 MHz CRYSTAL
STATUS
WITH 20pF LOAD CAPACITANCE
BUZZER CONNECTOR

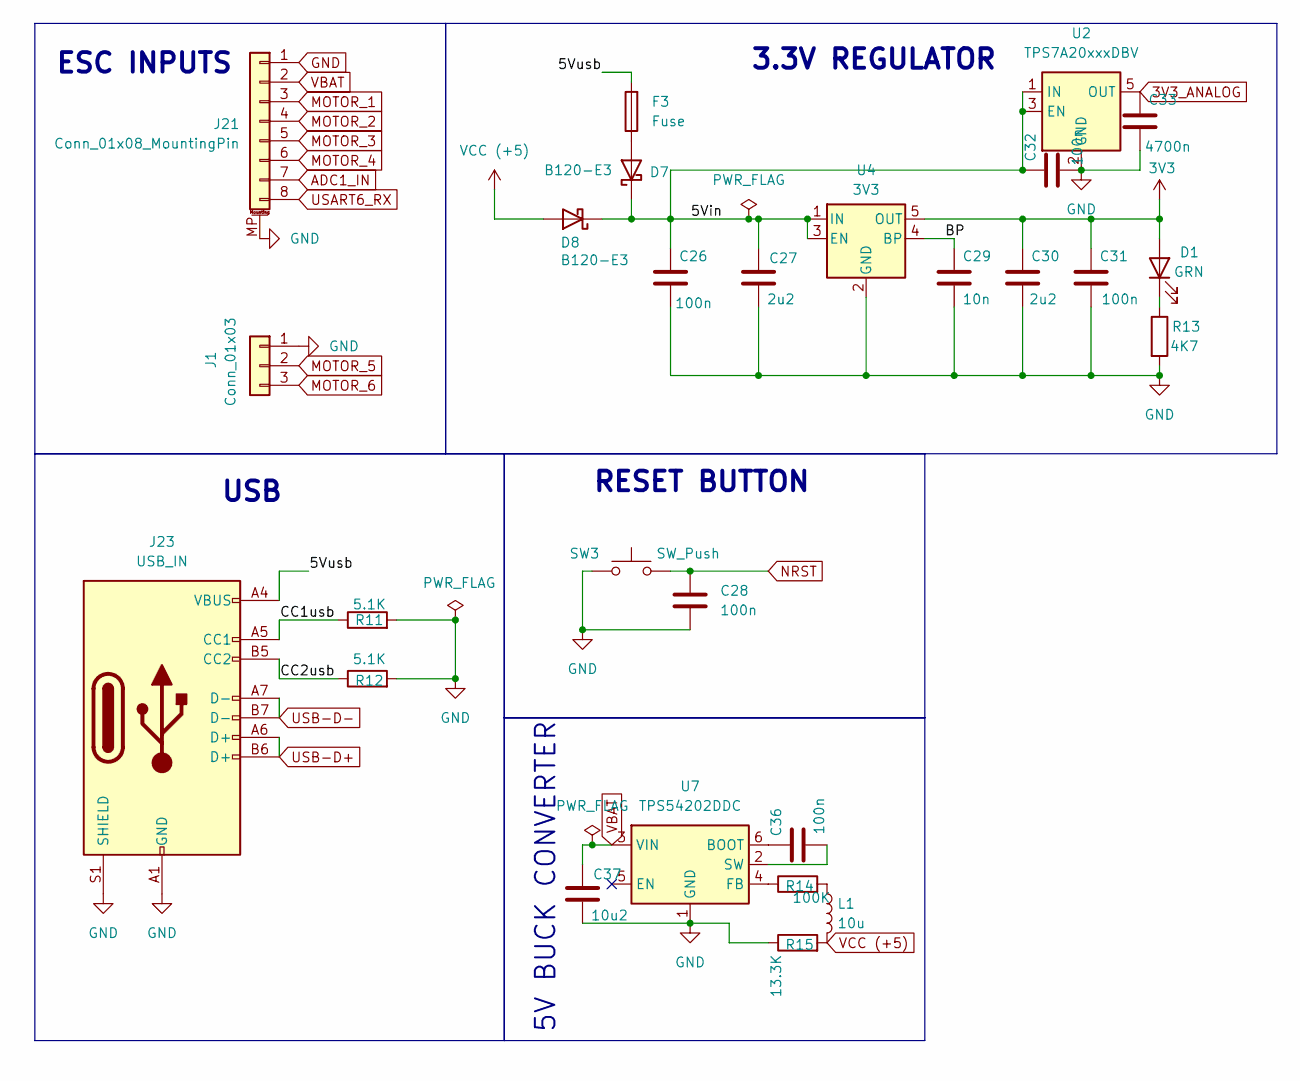
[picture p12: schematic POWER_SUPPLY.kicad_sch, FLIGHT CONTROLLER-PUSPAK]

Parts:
C26, C28, C31, C32, C36: 100n; C_0402_1005Metric
C27, C30: 2u2; C_0603_1608Metric
C29: 10n; C_0402_1005Metric
C33: 4700n; C_0402_1005Metric
C37: 10u2; C_0603_1608Metric
D1: GRN; LED_0603_1608Metric
D7, D8: B120-E3; D_0603_1608Metric
F3: Fuse; Fuse_1206_3216Metric
J1: Conn_01x03; PinHeader_1x03_P2.54mm_Vertical
J21: Conn_01x08_MountingPin; JST_SH_BM08B-SRSS-TB_1x08-1MP_P1.00mm_Vertical
J23: USB_IN; USB_C_Receptacle_GCT_USB4105-xx-A_16P_TopMnt_Horizontal
L1: 10u; L_APV_ANR252012
R11, R12: 5.1K; R_0402_1005Metric
R13: 4K7; R_0402_1005Metric
R14: 100K; R_0402_1005Metric
R15: 13.3K; R_0402_1005Metric
SW3: SW_Push; SW_Push_1TS009xxxx-xxxx-xxxx_6x6x5mm
U2: TPS7A20xxxDBV; SOT-23-5
U4: 3V3; SOT-23-5
U7: TPS54202DDC; SOT-23-6

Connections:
3V3: C30.1, C31.1, D1.2 (A), U4.5 (OUT); also elsewhere on the board
3V3_ANALOG: C33.1, U2.5 (OUT); also elsewhere on the board
/POWER SUPPLY/5Vin: C26.1, C27.1, C32.1, D7.1 (K), D8.1 (K), U2.1 (IN), U2.3 (EN), U4.1 (IN), U4.3 (EN)
/POWER SUPPLY/5Vusb: F3.2, J23.A4 (VBUS), J23.A9 (VBUS), J23.B4 (VBUS), J23.B9 (VBUS)
/POWER SUPPLY/BP: C29.1, U4.4 (BP)
/POWER SUPPLY/CC1usb: J23.A5 (CC1), R11.1
/POWER SUPPLY/CC2usb: J23.B5 (CC2), R12.1
ADC1_IN: J21.7
GND: C26.2, C27.2, C28.2, C29.2, C30.2, C31.2, C32.2, C33.2, C37.2, J1.1, J21.1, J21.MP (MountPin), J23.A1 (GND), J23.A12 (GND), J23.B1 (GND), J23.B12 (GND), J23.S1 (SHIELD), R11.2, R12.2, R13.2, R15.1, SW3.1, U2.2 (GND), U4.2 (GND), U7.1 (GND); also elsewhere on the board
MOTOR_1: J21.3; also elsewhere on the board
MOTOR_2: J21.4; also elsewhere on the board
MOTOR_3: J21.5; also elsewhere on the board
MOTOR_4: J21.6; also elsewhere on the board
MOTOR_5: J1.2; also elsewhere on the board
MOTOR_6: J1.3; also elsewhere on the board
NRST: C28.1, SW3.2; also elsewhere on the board
unnamed: D1.1 (K), R13.1
unnamed: D7.2 (A), F3.1
unnamed: L1.1, R14.2
unnamed: C36.1, U7.6 (BOOT)
unnamed: R14.1, U7.4 (FB)
unnamed: C36.2, U7.2 (SW)
USART6_RX: J21.8; also elsewhere on the board
USB-D+: J23.A6 (D+), J23.B6 (D+); also elsewhere on the board
USB-D-: J23.A7 (D-), J23.B7 (D-); also elsewhere on the board
VBAT: C37.1, J21.2, U7.3 (VIN)
VCC (+5): D8.2 (A), L1.2, R15.2; also elsewhere on the board

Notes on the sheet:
USB
RESET BUTTON
ESC INPUTS
5V BUCK CONVERTER
3.3V REGULATOR

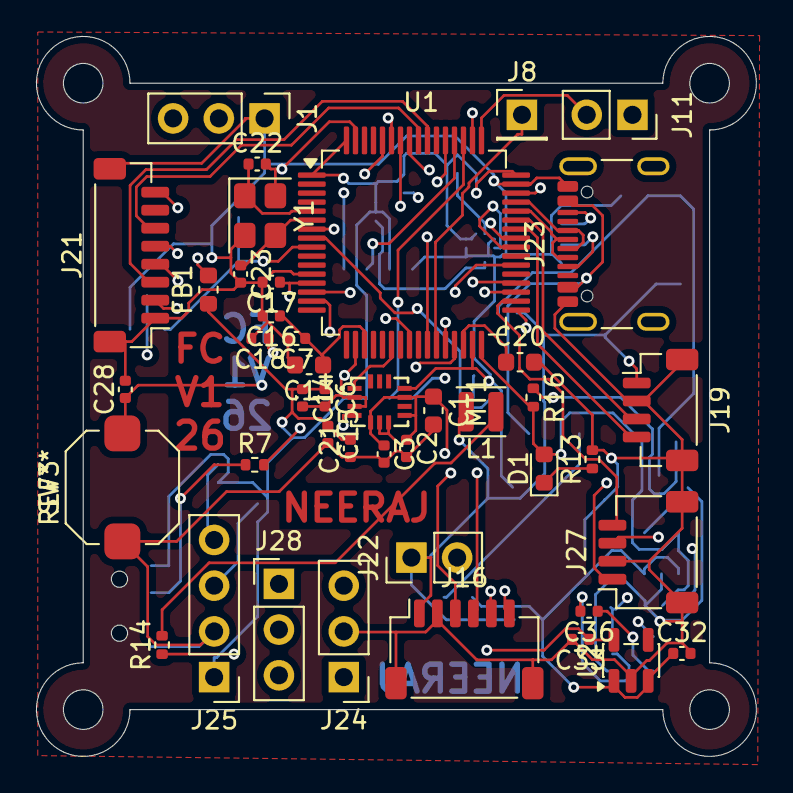
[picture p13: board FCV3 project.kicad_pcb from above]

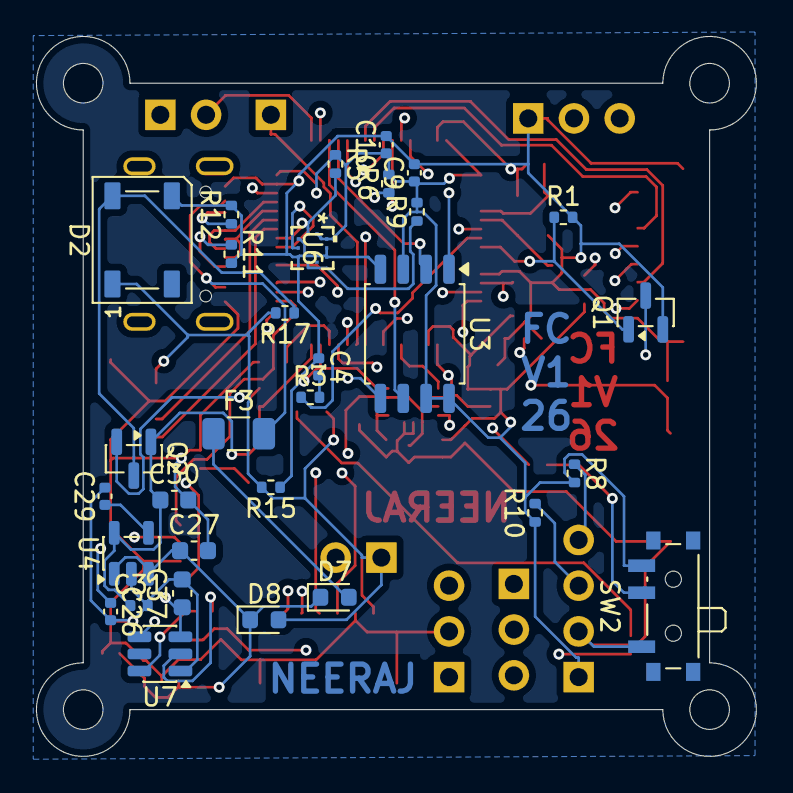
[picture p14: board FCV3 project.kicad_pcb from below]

Board: 4 copper layers, 40.0 x 40.0 mm, 78 parts (31 on the bottom side), 62 nets.

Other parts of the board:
C1: 2u2; C_0603_1608Metric
C2, C9, C10: 100n; C_0402_1005Metric
C3: 10n; C_0402_1005Metric
MT1: ICM-42688-P; LGA-14_L3.0-W2.5-P0.50-BL
R5, R6: 4K7; R_0402_1005Metric
R9: 100K; R_0402_1005Metric
U6: BMP390; 10LGA_2X2X0p75_BOS-L

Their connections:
3V3: C9.1, C10.1, R5.1, R6.2, R9.2, U6.1 (VDDIO), U6.10 (VDD); also elsewhere on the board
3V3_ANALOG: C1.1, C2.1, C3.1, MT1.5 (VDDIO), MT1.8 (VDD), MT1.10 (RESV__2); also elsewhere on the board
GND: C1.2, C2.2, C3.2, C9.2, C10.2, MT1.2 (RESV), MT1.3 (RESV__1), MT1.6 (GND), MT1.7 (FSYNC), MT1.11 (RESV__3), U6.3 (VSS), U6.5 (SDO), U6.8 (VSS), U6.9 (VSS); also elsewhere on the board
I2C3_SCL: R5.2, U6.2 (SCK); also elsewhere on the board
I2C3_SDA: R6.1, U6.4 (SDI); also elsewhere on the board
IMU_INT: MT1.4 (INT1/INT); also elsewhere on the board
unnamed: R9.1, U6.6 (CSB)
SPI1_MISO: MT1.1 (AP_SDO/AP_AD0); also elsewhere on the board
SPI1_MOSI: MT1.14 (AP_SDA/AP_SDIO/AP_SDI); also elsewhere on the board
SPI1_NSS: MT1.12 (AP_CS); also elsewhere on the board
SPI1_SCK: MT1.13 (AP_SCL/AP_SCLK); also elsewhere on the board

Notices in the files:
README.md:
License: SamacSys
